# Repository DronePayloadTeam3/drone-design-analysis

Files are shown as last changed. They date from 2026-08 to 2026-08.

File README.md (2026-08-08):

# Solution to Classroom Challenge Project — Drone Payload Capacity and Structural Design Analysis — Team 3

MATLAB-based UAV arm design and optimization project using CAD modeling, thrust-to-weight analysis, finite element analysis (FEA), and material cost optimization to evaluate structural performance and payload capacity.

This project was completed as part of the MathWorks Classroom Challenge and demonstrates the application of CAD modeling, MATLAB programming, thrust-to-weight analysis, and finite element analysis (FEA) to optimize UAV drone arm performance.

---

# Project Objective

The objective of this project is to design and evaluate a quadcopter drone arm that maximizes payload capacity while maintaining safe flight performance and structural integrity. Two distinct drone arm geometries were evaluated using six different engineering materials through thrust-to-weight analysis and Finite Element Analysis (FEA).

Through the development and analysis of these designs, the project investigates how geometry and material selection affect payload capacity, factor of safety, material cost, structural displacement, and stress distribution (e.g., Von Mises stress). Through analytical calculations and computational modeling, this project identifies the drone arm design that best provides effective payload capacity and structural integrity while optimizing material cost.

---

# MATLAB is used throughout this project to:

* Perform thrust-to-weight analysis
* Perform Finite Element Analysis (FEA)
* Perform material cost optimization

---

# Repository Structure

## [CAD-Designs](https://github.com/DronePayloadTeam3/drone-design-analysis/tree/main/CAD-Designs)

Contains all CAD models and design sketches.

### [Design-1-Hollow-Tapered-Rectangular-Tube](https://github.com/DronePayloadTeam3/drone-design-analysis/tree/main/CAD-Designs/Design-1-Hollow-Tapered-Rectangular-Tube)

* [Design_1_CAD_Model.STEP](https://github.com/DronePayloadTeam3/drone-design-analysis/blob/main/CAD-Designs/Design-1-Hollow-Tapered-Rectangular-Tube/Design_1_CAD_Model.STEP)
* [Design_1_Concept_Sketch.pdf](https://github.com/DronePayloadTeam3/drone-design-analysis/blob/main/CAD-Designs/Design-1-Hollow-Tapered-Rectangular-Tube/Design_1_Concept_Sketch.pdf)
* [Visualization_Only_Model.STL](https://github.com/DronePayloadTeam3/drone-design-analysis/blob/main/CAD-Designs/Design-1-Hollow-Tapered-Rectangular-Tube/Visualization_Only_Model.STL) — STL export for visual purposes only on GitHub.

### [Design-2-Hollow-Truss-Structure](https://github.com/DronePayloadTeam3/drone-design-analysis/tree/main/CAD-Designs/Design-2-Hollow-Truss-Structure)

* [Design_2_CAD_Model.STL](https://github.com/DronePayloadTeam3/drone-design-analysis/blob/main/CAD-Designs/Design-2-Hollow-Truss-Structure/Design_2_CAD_Model.STL)
* [Design_2_Concept_Sketch.pdf](https://github.com/DronePayloadTeam3/drone-design-analysis/blob/main/CAD-Designs/Design-2-Hollow-Truss-Structure/Design_2_Concept_Sketch.pdf)

## [Documentation](https://github.com/DronePayloadTeam3/drone-design-analysis/tree/main/Documentation)

Contains supporting project documentation.

* [Drone_Design_Constraints_Assumptions_and_Ideas.xlsx](https://github.com/DronePayloadTeam3/drone-design-analysis/blob/main/Documentation/Drone_Design_Constraints_Assumptions_and_Ideas.xlsx) — Supporting project document containing initial drone design constraints, assumptions, material information, and related design resources used during development.
* [Drone_Payload_Team_3_TOA.pdf](https://github.com/DronePayloadTeam3/drone-design-analysis/blob/main/Documentation/Drone_Payload_Team_3_TOA.pdf) — Team agreement documenting the project's organization, responsibilities, and project expectations.

## [MATLAB](https://github.com/DronePayloadTeam3/drone-design-analysis/tree/main/MATLAB)

Contains all MATLAB files used throughout the project.

* [droneArmMaterials.mat](https://github.com/DronePayloadTeam3/drone-design-analysis/blob/main/MATLAB/droneArmMaterials.mat) — Material properties database used throughout the analysis.
* [DroneDesign_Team3_Analysis.mlx](https://github.com/DronePayloadTeam3/drone-design-analysis/blob/main/MATLAB/DroneDesign_Team3_Analysis.mlx) — Main MATLAB Live Script containing the complete drone design, analysis, and optimization workflow.

### [Live-Script-PDF-Exports](https://github.com/DronePayloadTeam3/drone-design-analysis/tree/main/MATLAB/Live-Script-PDF-Exports)

Contains PDF exports of the MATLAB Live Script analysis for each drone arm design.

* [Design_1_Live_Script_Analysis_Export.pdf](https://github.com/DronePayloadTeam3/drone-design-analysis/blob/main/MATLAB/Live-Script-PDF-Exports/Design_1_Live_Script_Analysis_Export.pdf) — PDF export of the MATLAB analysis using Design 1.
* [Design_2_Live_Script_Analysis_Export.pdf](https://github.com/DronePayloadTeam3/drone-design-analysis/blob/main/MATLAB/Live-Script-PDF-Exports/Design_2_Live_Script_Analysis_Export.pdf) — PDF export of the MATLAB analysis using Design 2.

## [Results](https://github.com/DronePayloadTeam3/drone-design-analysis/tree/main/Results)

Contains all exported project results organized by drone design.

* [Design-1-Results](https://github.com/DronePayloadTeam3/drone-design-analysis/tree/main/Results/Design-1-Results) — Contains maximum payload capacity, material cost optimization, and FEA results for Design 1.
* [Design-2-Results](https://github.com/DronePayloadTeam3/drone-design-analysis/tree/main/Results/Design-2-Results) — Contains maximum payload capacity, material cost optimization, and FEA results for Design 2.

An example of the exported FEA results is shown below for Design 1 using Fiberglass Composite (GFRP):

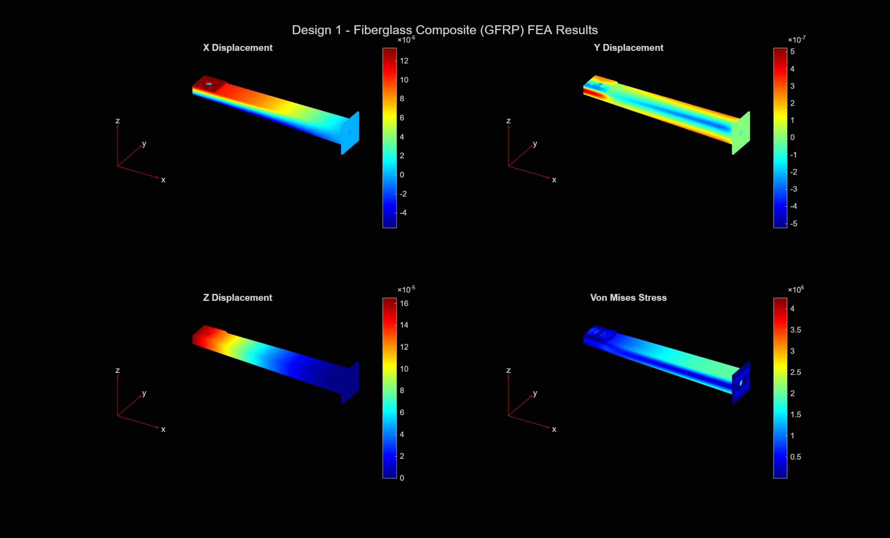
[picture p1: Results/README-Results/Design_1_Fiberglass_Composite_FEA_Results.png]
Design 1 Fiberglass Composite FEA Results


---

# CAD Download Instructions

1. Open the [CAD-Designs](https://github.com/DronePayloadTeam3/drone-design-analysis/tree/main/CAD-Designs) folder.
2. Open the [Design-1-Hollow-Tapered-Rectangular-Tube](https://github.com/DronePayloadTeam3/drone-design-analysis/tree/main/CAD-Designs/Design-1-Hollow-Tapered-Rectangular-Tube) or [Design-2-Hollow-Truss-Structure](https://github.com/DronePayloadTeam3/drone-design-analysis/tree/main/CAD-Designs/Design-2-Hollow-Truss-Structure) folder.
3. Select the desired STEP (for Design 1) or STL (for Design 2) file.
4. Click **Download Raw File** (download icon) in the upper-right corner.

   * Alternatively, right-click **Raw** and choose **Save Link As...**

**Note:** The `Visualization_Only_Model.STL` file for Design 1 is provided for visualization purposes only and is not intended to be used as the primary CAD model.

---

# Project Solution Instructions

1. Open MATLAB.

2. Place the project files in a working folder while maintaining the repository's file structure.

3. Open the [DroneDesign_Team3_Analysis.mlx](https://github.com/DronePayloadTeam3/drone-design-analysis/blob/main/MATLAB/DroneDesign_Team3_Analysis.mlx) Live Script.

4. Ensure the following files are available at their corresponding repository locations:

  * [droneArmMaterials.mat](https://github.com/DronePayloadTeam3/drone-design-analysis/blob/main/MATLAB/droneArmMaterials.mat)
  * [Design_1_CAD_Model.STEP](https://github.com/DronePayloadTeam3/drone-design-analysis/blob/main/CAD-Designs/Design-1-Hollow-Tapered-Rectangular-Tube/Design_1_CAD_Model.STEP)
  * [Design_2_CAD_Model.STL](https://github.com/DronePayloadTeam3/drone-design-analysis/blob/main/CAD-Designs/Design-2-Hollow-Truss-Structure/Design_2_CAD_Model.STL)

5. Select which drone arm design you would like to analyze during **Task 4: Finite Element Analysis (FEA)**.

   To switch between the two drone arm designs, locate the design selection in the Live Script.

   **For Design 1:**

   ```matlab
   selectedDesign = "Design 1";
   % selectedDesign = "Design 2";
   ```

   **For Design 2:**

   ```matlab
   % selectedDesign = "Design 1";
   selectedDesign = "Design 2";
   ```

   Only one design should remain uncommented before running the script. Design 1 is selected by default, as it is the final recommended design for this project.

6. Click **Run**.

The Live Script automatically generates:

* Payload summary tables
* Maximum payload comparison charts
* FEA displacement plots
* Von Mises stress plots
* FEA results tables
* Material cost comparison charts
* Material cost optimization tables
* Final design recommendation

All exported figures, tables, and analysis outputs can be found in the [Results](https://github.com/DronePayloadTeam3/drone-design-analysis/tree/main/Results) folder, organized separately for Design 1 and Design 2.

---

# Project Workflow

## 1. Gather Assumptions and Load Material Properties

Defines the drone design assumptions, component masses, thrust capacity, and project constraints, then loads the material properties used throughout the analysis.

The analysis considers six materials:

* Carbon Fiber Composite (CFRP)
* Aluminum Alloy
* Fiberglass Composite (GFRP)
* PLA Plastic
* ABS Plastic
* Wood (Birch)

The project parameters include:

* Quadcopter configuration with four motors and four propellers
* Maximum thrust of **1 kg per motor**
* Base drone mass of **1 kg**, excluding arms and payload
* Minimum payload requirement of **0.5 kg**
* Minimum thrust-to-weight ratio of **2:1**
* Four drone arms

Material properties used in the analysis include density, Young's modulus, Poisson's ratio, yield strength, and average material cost.

## 2. Propose Two Drone Arm Designs

Develops and compares two distinct drone arm geometries through CAD models and design sketches.

**Design 1** is a tapered hollow rectangular tube designed to strategically reduce material toward the motor mount while maintaining greater structural reinforcement near the drone body connection.

**Design 2** is a hollow truss-shaped structure designed to reduce mass while providing additional structural reinforcement through internal truss members.

The two designs are evaluated based on their geometry, volume, structural behavior, and suitability for the required loading conditions.

## 3. Perform Thrust-to-Weight Analysis

Calculates the maximum payload capacity for each combination of drone arm design and material.

The analysis evaluates both arm geometries across all six material options and determines whether each combination satisfies:

* Minimum payload requirement of **0.5 kg**
* Minimum thrust-to-weight ratio of **2:1**

The results are presented using summary tables and payload comparison plots.

## 4. Perform Finite Element Analysis (FEA)

Performs a structural finite element analysis on a single drone arm for the selected design.

The model:

* Imports the corresponding CAD geometry into MATLAB
* Generates a finite element mesh
* Fixes the arm at the attachment point to the drone body
* Applies the upward motor thrust and downward motor weight to the motor mounting face
* Evaluates the arm using all six material options

The analysis calculates:

* Maximum displacement
* Maximum Von Mises stress
* Factor of Safety

The results are presented using numerical summary tables and displacement and Von Mises stress visualizations.

## 5. Optimize Material Cost

Uses the results from the thrust-to-weight analysis and FEA to identify material options that satisfy the required payload, thrust-to-weight ratio, and Factor of Safety requirements.

The total material cost is then calculated for each material option based on the arm geometry, material cost, and four-arm configuration. The valid material options are compared to identify the lowest-cost solution while considering structural performance and engineering practicality.

## 6. Recommend a Final Design Solution

Interprets the results from the thrust-to-weight analysis, FEA, and material cost optimization to select the final drone arm geometry and material.

The final recommendation considers quantitative performance, structural safety, material cost, manufacturability, and practical engineering limitations.

---

# Required Software

* MATLAB R2026a

---

# Required Toolboxes

* Partial Differential Equation Toolbox

---

# References

* [MathWorks Classroom Challenge Project Hub: Drone Payload Capacity and Structural Design Analysis](https://github.com/mathworks/MATLAB-Simulink-Challenge-Project-Hub/tree/main/Classroom%20Challenge%20Projects/Projects/Drone%20Payload%20Capacity%20and%20Structural%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) — Original MathWorks Classroom Challenge project page containing the project challenge and associated project information.

* [Drone Design Constraints, Assumptions, and Ideas](https://github.com/DronePayloadTeam3/drone-design-analysis/blob/main/Documentation/Drone_Design_Constraints_Assumptions_and_Ideas.xlsx) — Supporting project document containing initial drone design constraints, assumptions, material information, and related design resources used during the development of the project.

* [Drone Payload Team 3 Team Agreement](https://github.com/DronePayloadTeam3/drone-design-analysis/blob/main/Documentation/Drone_Payload_Team_3_TOA.pdf) — Team agreement documenting the project's organization, responsibilities, and project expectations.

---

# Contact

For any questions regarding this repository or how to run the project, please contact the team at:

**[boulaetans@gmail.com](mailto:boulaetans@gmail.com)**

---

# License

This project is distributed under the license included in the repository.

See the [LICENSE](https://github.com/DronePayloadTeam3/drone-design-analysis/blob/main/LICENSE) file for the full license terms.

---

# Final Recommendation

Based on the thrust-to-weight analysis, Finite Element Analysis (FEA), and material cost optimization, the recommended design is **Design 1, a tapered hollow rectangular arm** constructed from **Fiberglass Composite (GFRP)**. It provides the best balance of payload capacity, structural safety, and engineering performance while satisfying all project constraints.

Although Carbon Fiber Composite (CFRP) provided the highest overall structural performance, GFRP offered a better balance between performance and cost while still meeting all project requirements. The improvements provided by CFRP were relatively small compared to its increase in material cost, making GFRP the more practical engineering choice.

Additionally, while Wood (Birch) was identified as the lowest-cost material, it was not selected as the final recommendation. Although it satisfied the project requirements under the simplified loading conditions, it was not considered the best choice for real-world drone applications where additional engineering conditions such as wind, vibration, fatigue, and landing impacts must be considered. Furthermore, wood can absorb moisture from the environment, which may reduce structural performance over time while increasing the overall weight of the drone. For these reasons, GFRP was considered the strongest overall engineering solution.

Compared with Design 2, Design 1 demonstrated better structural behavior. Although Design 2 met the project requirements, it experienced greater maximum displacement. Through investigation, it was determined that the truss members primarily reinforced the x- and y-directions but provided limited resistance in the z-direction. This reduced the arm's resistance to vertical bending and likely contributed to the higher displacement. Rather than redesigning the arm, the team chose to retain the original design because it demonstrates the engineering design process. The results highlighted how analysis, testing, and iteration lead to improved engineering decisions and provide valuable lessons for future designs.

Overall, Design 1 with GFRP provided the best combination of payload capacity, structural integrity, manufacturability, and material cost. Future work could expand this analysis by incorporating wind loading, vibration, fatigue, landing impacts, motor torque, and experimental prototype testing to better represent real operating conditions.

A more detailed report of the final design recommendation, including the MATLAB-based analysis, FEA results, and optimization process, can be found in the accompanying MATLAB Live Script.

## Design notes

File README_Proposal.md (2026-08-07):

# Drone-Design-Analysis-Team-3

MATLAB-based UAV arm design and optimization project using CAD modeling, thrust-to-weight analysis, finite element analysis (FEA), and material cost optimization to evaluate structural performance and payload capacity.

This project was completed as part of the MathWorks Classroom Challenge and demonstrates the application of CAD modeling, MATLAB programming, thrust-to-weight analysis, and finite element analysis (FEA) to optimize UAV drone arm performance.

---

# Project Objective

The objective of this project is to design and evaluate a quadcopter drone arm that maximizes payload capacity while maintaining safe flight performance and structural integrity. Two distinct drone arm geometries were evaluated using six different engineering materials through thrust-to-weight analysis and Finite Element Analysis (FEA).

Through the development and analysis of these designs, the project investigates how geometry and material selection affect payload capacity, factor of safety, material cost, structural displacement, and stress distribution (e.g., Von Mises stress). Through analytical calculations and computational modeling, this project identifies the drone arm design that best provides effective payload capacity and structural integrity while optimizing material cost.

---

# MATLAB is used throughout this project to:

- Perform thrust-to-weight analysis
- Perform Finite Element Analysis (FEA)
- Perform material cost optimization

---

# Repository Structure

## CAD-Designs

Contains all CAD models and design sketches.

- Design_1_CAD_Model.STEP
- Design_2_CAD_Model.STEP
- Design_1_Concept_Sketch.pdf
- Design_2_Concept_Sketch.pdf

## Documentation

Contains supporting project documentation.

- Team Agreement Form
- Initial assumptions and constraints
- Brainstorming and drone design concepts

## MATLAB

Contains all MATLAB files used throughout the project.

- DroneDesign_Team3_Analysis.mlx – Main MATLAB Live Script containing the complete drone design, analysis, and optimization workflow.
- DroneDesign1_Team3_Analysis.pdf – PDF export of the Design 1 MATLAB analysis.
- DroneDesign2_Team3_Analysis.pdf – PDF export of the Design 2 MATLAB analysis.
- droneArmMaterials.mat – Material properties database used throughout the analysis.

## Results

Contains all exported project results organized by drone design.

Each design folder contains:

- Charts
- FEA plots
- FEA result tables
- Maximum payload tables
- Material cost optimization tables

---

# How to Download the CAD Files

1. Open the **Drone CAD Designs** folder.
2. Select the desired STEP and STL file.
3. Click **Download Raw File** (download icon) in the upper-right corner.
4. Alternatively, right-click **Raw** and choose **Save Link As...**

---

# How to Run the Project

1. Open MATLAB.

2. Place all project files in the same working folder.

3. Open DroneDesign_Team3_Analysis.mlx.

4. Ensure the following files are located in the working directory:
- droneArmMaterials.mat
- Design_1_CAD_Model.STEP
- Design_2_CAD_Model.STL

6. Open **DroneDesign_Team3_Analysis.mlx**.

7. Select which drone arm design you would like to analyze during **Task 4: Finite Element Analysis (FEA)**.

To switch between the two drone arm designs, locate the STEP file assignment in the Live Script.

For Design 1:

```matlab
selectedDesign = "Design 1";
% selectedDesign = "Design 2";
```

For Design 2:

```matlab
% selectedDesign = "Design 1";
selectedDesign = "Design 2";
```

Only one design should remain uncommented before running the script.

6. Click **Run**.

---

# Project Workflow

## 1. Load Material Properties

Loads the density, Young's modulus, Poisson's ratio, yield strength, and material cost for:

- Carbon Fiber Composite (CFRP)
- Aluminum Alloy
- Fiberglass Composite (GFRP)
- PLA Plastic
- ABS Plastic
- Wood (Birch)

---

## 2. Thrust-to-Weight Analysis

Calculates the mass of each drone arm and determines the maximum payload capacity while verifying that each design satisfies:

- Minimum payload requirement of **0.5 kg**
- Minimum thrust-to-weight ratio of **2:1**

---

## 3. Finite Element Analysis (FEA)

Imports the selected STEP or STL model into MATLAB.

The script then:

- Generates the finite element mesh
- Applies boundary conditions
- Applies motor thrust and motor weight
- Computes:
  - Maximum displacement
  - Von Mises stress
  - Factor of Safety

The results are displayed as summary tables and interactive displacement and stress plots.

---

## 4. Material Cost Optimization

After completing the thrust-to-weight analysis and FEA, MATLAB calculates the material cost for each design based on the arm geometry and material properties.

The program filters materials that satisfy all project constraints and identifies the lowest-cost engineering solution.

---

# Required Software

- MATLAB R2026a

---

# Required Toolboxes

- Partial Differential Equation Toolbox
- MATLAB Live Editor

---

# How to Reproduce the Results

To reproduce the project results:

1. Use the provided **droneArmMaterials.mat** database.
2. Use the provided CAD models.
3. Open **DroneDesign_Team3_Analysis.mlx**.
4. Select either Design 1 or Design 2 by commenting/uncommenting the corresponding STEP file.
5. Run the Live Script without modifying any input parameters.

The Live Script automatically generates:

- Payload summary tables
- Maximum payload comparison charts
- Material cost comparison charts
- FEA displacement plots
- Von Mises stress plots
- FEA results tables
- Material cost optimization tables
- Final design recommendation

All exported figures, tables, and analysis outputs can be found in the **Results** folder, organized separately for Design 1 and Design 2.

---

# Final Recommendation

Based on the thrust-to-weight analysis, Finite Element Analysis (FEA), and material cost optimization, the recommended design is **Design 1, a tapered hollow rectangular arm** constructed from **Fiberglass Composite (GFRP)**. It provides the best balance of payload capacity, structural safety, and engineering performance while satisfying all project constraints.

Although Carbon Fiber Composite (CFRP) provided the highest overall structural performance, GFRP offered a better balance between performance and cost while still meeting all project requirements. The improvements provided by CFRP were relatively small compared to its increase in material cost, making GFRP the more practical engineering choice.

Additionally, while Wood (Birch) was identified as the lowest-cost material, it was not selected as the final recommendation. Although it satisfied the project requirements under the simplified loading conditions, it was not considered the best choice for real-world drone applications where additional engineering conditions such as wind, vibration, fatigue, and landing impacts must be considered. Furthermore, wood can absorb moisture from the environment, which may reduce structural performance over time while increasing the overall weight of the drone. For these reasons, GFRP was considered the strongest overall engineering solution.

Compared with Design 2, Design 1 demonstrated better structural behavior. Although Design 2 met the project requirements, it experienced greater maximum displacement. Through investigation, it was determined that the truss members primarily reinforced the x- and y-directions but provided limited resistance in the z-direction. This reduced the arm's resistance to vertical bending and likely contributed to the higher displacement. Rather than redesigning the arm, the team chose to retain the original design because it demonstrates the engineering design process. The results highlighted how analysis, testing, and iteration lead to improved engineering decisions and provide valuable lessons for future designs.

Overall, Design 1 with GFRP provided the best combination of payload capacity, structural integrity, manufacturability, and material cost. Future work could expand this analysis by incorporating wind loading, vibration, fatigue, landing impacts, motor torque, and experimental prototype testing to better represent real operating conditions.

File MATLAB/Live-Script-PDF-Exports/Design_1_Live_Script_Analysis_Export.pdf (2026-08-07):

## Drone Payload Structure Design and Analysis

In this project, you are optimizing drone arm design, including geometry and material selection, to maximize payload capacity while ensuring structural integrity under motor-induced loads. You will use MATLAB to perform force balance analysis and finite element modeling to quantitatively support your design solution.

Use this Live Script as a template to get started on your project solution. You may include helper functions at the bottom of this document or as separate files. For a tutorial on how to use Live Scripts, check out this video. (https://www.youtube.com/watch?v=hUXTyPYRidM)

Suggested Tasks

1. Gather your starter assumptions and load the material properties into MATLAB.
2. Propose at least two drone arm designs
3. Perform a thrust-to-weight analysis to evaluate each of your designs across all material options. Your design must meet a minimum payload requirement and safety standards.
4. Perform finite element analysis across all design and material options.
5. Recommend a final design solution.

Table of Contents

## Break Down the Problem

In the space below, define the problem statement:

The objective is to select a drone arm geometry and material combination that maximizes payload capacity while satisfying the minimum thrust-to-weight ratio and maintaining an acceptable structural safety factor under motor loading.

List the requirements, constraints, and success criteria for the project:

- The drone must support a minimum payload of 0.5 kg.
- The drone must meet a thrust-to-weight ratio of at least 2:1.
- The quadcopter configuration uses 4 motors and 4 propellers.
- Each motor can provide up to 1 kg of thrust.
- The total mass of the drone without arms or payload is 1 kg.
- The design must use at least two distinct arm geometries.
- The arm design must be evaluated across the available material options.
- The final selected design must satisfy the required payload and flight safety constraints.

- The structural design must maintain an acceptable factor of safety, with the target engineering range taken as approximately ~1.5-2+.
- Material cost should be considered as an optional optimization criterion in addition to the required performance and safety checks.

What is your proposed solution?

- The proposed solution is to compare two distinct drone arm geometries and evaluate them across the available material options using thrust-to-weight analysis and a single-arm finite element model to identify the combination that maximizes payload capacity while satisfying the required flight and structural safety constraints.

List the steps you will need to take to achieve your proposed solution:

1. Gather Starter Assumptions and Load Properties into MATLAB
2. Develop at Least Two Distinct Drone Arm Designs in CAD or by Hand
3. Write a MATLAB Function to Perform a Thrust-to-Weight Analysis Across All Design and Material Options
4. Create a 3D Model of One Drone Arm Using CAD Software of Your Choice
5. Import Your Model into MATLAB and Perform FEA
6. Report the Overall Maximum Displacement, Maximum Stress, and Factor of Safety for Each Design and Material Combination, Including Visualizations of the X-, Y-, and Z-Displacement and von Mises Stress
7. Recommend a Final Drone Arm Design That Meets All Required Constraints

What challenges do you face in the process of achieving the solution?

- The analysis is simplified to a single-arm structural model rather than the full four-arm drone assembly.
- Material properties are treated as homogeneous and isotropic, which is an approximation for composite and wood materials.
- The arm geometry and loading conditions are idealized rather than fully representing the complete flight environment.
- The FEA model captures only the dominant motor thrust and motor weight loading, while other real-world effects such as vibration, landing loads, and aerodynamic forces are not included.
- The design must balance payload capacity, structural stiffness, and material cost under the stated assumptions.

## Task 1: Gather your starter assumptions and load material properties

Load the provided droneArmMaterials.mat file into MATLAB. This contains a data struct with the material properties for six different materials commonly used for drones (carbon fiber composite, aluminum alloy, fiberglass composite, PLA plastic, ABS plastic, and wood). For each material, you have been provided the following information:

▪
Density ( ), in

- Young's Modulus (E) in Pa
- Poisson's ratio ( ), unitless
- Yield strength, in Pa
- Average cost per meter in US dollars

For this project, you can assume the following design parameters:

- Quadcopter drone with 4 motors and 4 propellers
- Each motor can provide up to 1kg thrust
▪
Acceleration due to gravity:
- Total weight of the drone components without the arms or the payload: 1kg

The breakdown of the weight of each drone component is as follow:

- Battery = 0.3kg
- Each motor = 65g, 4 motors = 0.26kg
- Each propeller = 10g, 4 propellers = 0.04 kg
- Each electronic speed controller = 30g, 4 electronic speed controllers = 0.12 kg
- Flight controller and electronics = 0.05kg
- Receiver/GPS = 0.03kg
- Drone frame (center body) excluding arms = 0.2kg

clc; clear; close all;

% Load material properties for the six drone arm materials load droneArmMaterials.mat;

% Define drone component masses (kg)
batteryMass = 0.30; % Battery
motorMass = 65 / 1000; % Each motor numberOfMotors = 4; % Number of motors totalMotorMass = motorMass * numberOfMotors;

propellerMass = 10 / 1000; % Each propeller
numberOfPropellers = 4; % Number of propellers
totalPropellerMass = propellerMass * numberOfPropellers;

speedControllerMass = 30 / 1000; % Each electronic speed controller numberOfSpeedControllers = 4; % Number of electronic speed controllers totalSpeedControllerMass = ...
speedControllerMass * numberOfSpeedControllers;

flightControllerMass = 0.05; % Flight controller and electronics receiverGPSMass = 0.03; % Receiver/GPS
droneFrameMass = 0.20; % Drone frame excluding arms

% Calculate total mass of the drone without arms or payload totalDroneMassWithoutArmsOrPayload = ...
batteryMass + ...
totalPropellerMass + ...
totalMotorMass + ...
totalSpeedControllerMass + ... flightControllerMass + ... receiverGPSMass + ...
droneFrameMass;

% Define general design parameters
gravity = 9.81; % Acceleration due to gravity (m/s^2) motorThrustCapacity = 1; % Maximum thrust per motor (kgf)
totalThrust = numberOfMotors * motorThrustCapacity;
minimumPayload = 0.5; % Minimum required payload (kg) requiredThrustToWeightRatio = 2; % Required thrust-to-weight ratio (2:1) numberOfArms = 4; % Number of arms on the quadcopter

## Task 2: Propose at least two drone arm designs

Develop at least two distinct drone arm designs by drawing clear, neatly labeled sketches that show key geometric features, including:

- Overall shape (e.g. beam, tube, truss structure)
- Dimensions (length, width, thickness)
- Motor mount location
- Where the arm connects to the drone body

The two designs should be meaningfully different from each other (e.g. different geometries or structural strategies) and not just small variations of the same idea.

Navigate to the 'Insert' tab and insert pictures of your sketches in the space below (hand-drawn or digital). Include a short design description for each sketch that includes:

- Geometry (e.g. solid beam, hollow tube, beam with trusses)
- Why you chose this design
- How it might perform under load

Note: All dimensions and measurements for the drone arm designs are provided in millimeters (mm) for consistency.

Drone Arm Design 1:

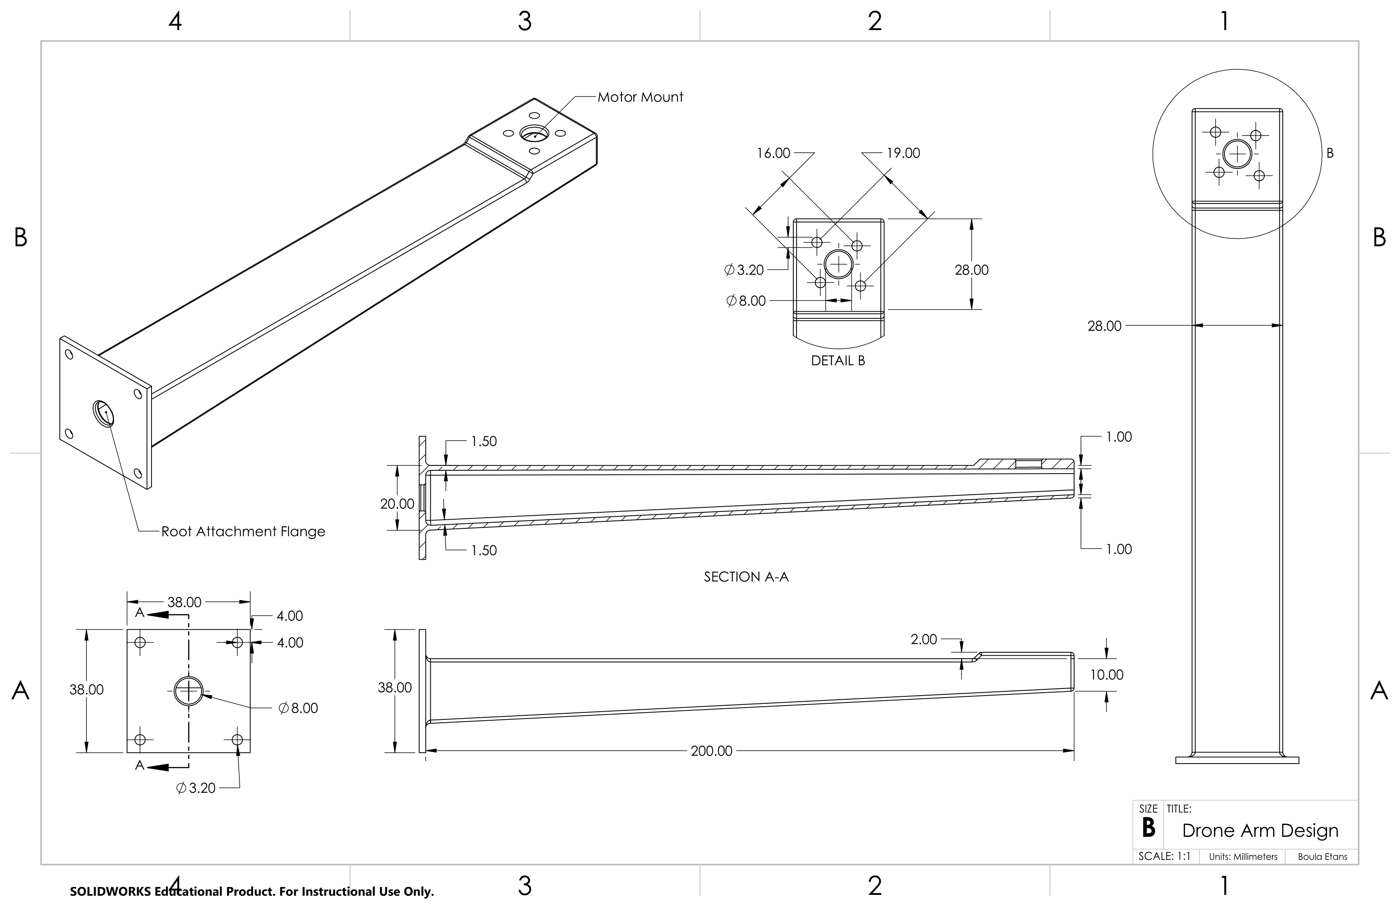
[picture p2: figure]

Geometry: A tapered hollow rectangular tube spanning a total length of 200.00 mm. The structure originates at the base with a 38.00 mm by 38.00 mm square attachment flange and a profile measuring 28.00 mm in width and 20.00 mm in height, featuring a wall thickness of 1.50 mm. It gracefully tapers toward the distal end to a profile measuring 28.00 mm in width and 10.00 mm in height, with a reduced wall thickness of 1.00 mm. The arm terminates in a 28.00 mm by 28.00 mm square motor mount platform positioned 2.00 mm above the top edge of the tapered body.

Reasoning: This geometry is chosen to optimize the strength-to-weight ratio. A drone arm acts as a cantilever beam, meaning the highest bending moments occur at the base where it attaches to the frame, while the stresses at the motor end are significantly lower. By tapering both the overall profile and the wall thickness, the design strategically places material only where it is needed to bear the load, stripping away unnecessary dead weight at the tip.

Analysis: Under the 1 kg upward thrust load, this arm is expected to show excellent bending stiffness at
the root, keeping overall deflections low. Because the tapered design minimizes the arm's total mass, it will consume less of the drone's 2 to 1 thrust-to-weight budget, maximizing the remaining capacity available to safely carry the required 0.5 kg payload.

Drone Arm Design 2:

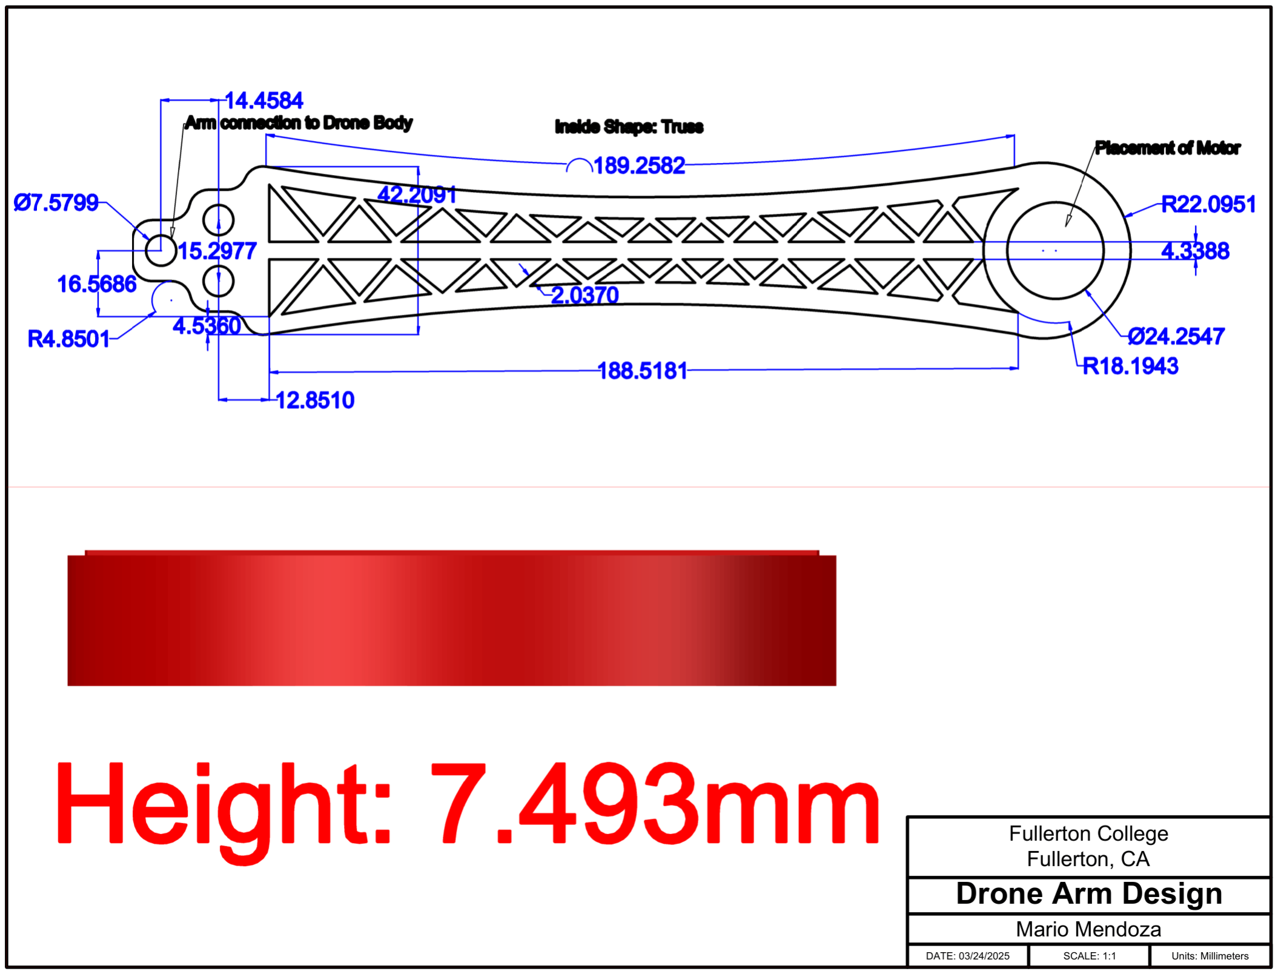
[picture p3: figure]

Geometry: A hollow, truss-shaped interior where each truss arm or branch has a thickness of approximately 2.0370 mm. The outside walls feature a continuous inward curve (with a radius of 189.2582 mm), causing the internal truss structure to narrow towards the middle before widening again as it approaches the motor housing. Holes for the arm connection are placed in a triangle shape. The total height of the drone arm is 7.493 mm throughout.

Reasoning: Truss shapes of the inside part of the drone arm are designed for stabilization, optimal strength, material efficiency, and weight reduction. This drone arm design also allows for creativity of the user or any future re-designers regarding the placement of the motor. The arm connection to the body of the drone is also shaped in a triangle to ensure the placement is optimally secured and geometrically rigid.

Analysis: While the truss structure of the drone arm design will provide strength and stiffness, the region between the arm connection and the starting portion of where the curvature begins might cause future problems; further optimization might be required in order to avoid a snap of that region.

## Task 3: Perform thrust-to-weight analysis across all design and material options

Write a MATLAB function that will perform a thrust-to-weight analysis across all design and material options. This analysis will help you evaluate which drone arm design and which material optimizes payload capacity while meeting suggested safety requirements.

- Your design must support a minimum payload of 0.5kg.
- Your design must meet a thrust-to-weight ratio of at least 2:1 to ensure safe and stable flight. This safety standard is widely used in drone design. Conceptually, it means that the drone's maximum thrust must be at least twice its weight. This ensures stable hovering and maneuvering with a safety margin. Note that the thrust-to-weight safety margin is a system-level safety standard for drone flight that is distinct from the structural safety factor of the drone arms (which you will evaluate later through finite element analysis).
- Your goal is calculate maximum payload capacity for each design and material option (i.e. what is the heaviest payload your drone design could carry while still allowing the drone to safely take off?)

Ensure that the results of your analysis can be readily interpreted, e.g. in the form of a summary table or plot.

Note: if you have two drone arm designs, the expected output should be 12 payload capacity estimates (2 designs across 6 materials options).

% Define arm volumes from Task 2
armVolume1 = 2.483207e-5;
armVolume2 = 3.4295614e-5;

% Store both design volumes for comparison armVolumes = [armVolume1, armVolume2];

% Define names for each drone arm design
designNames = ["Design 1", "Design 2"];

% Perform thrust-to-weight analysis for all designs and materials task3Results = thrustToWeightAnalysis( ...
armVolumes, ...
designNames, ...
materials, ...
totalDroneMassWithoutArmsOrPayload, ... totalThrust, ...
minimumPayload, ...
requiredThrustToWeightRatio, ... numberOfArms);

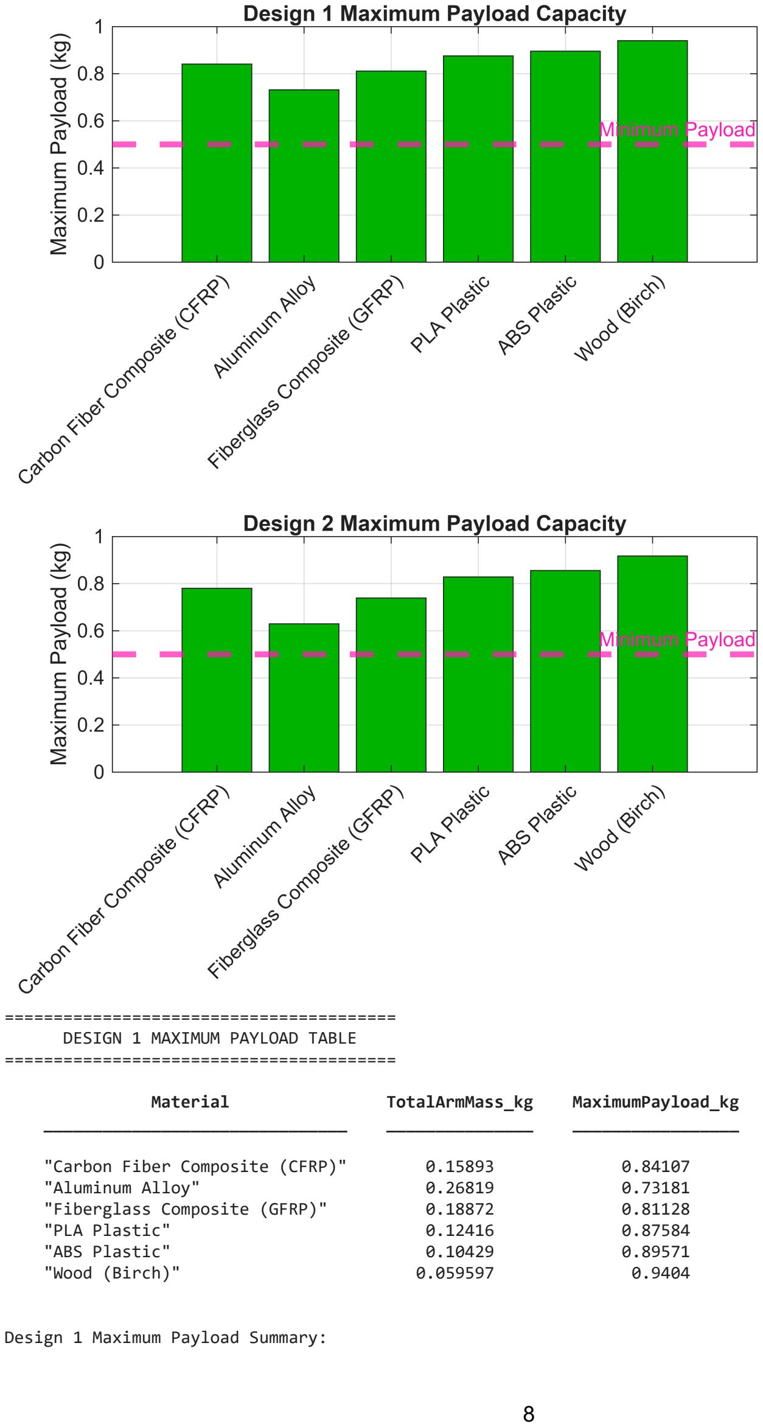
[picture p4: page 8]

======================================== DESIGN 1 MAXIMUM PAYLOAD TABLE ========================================

Material | TotalArmMass_kg | MaximumPayload_kg
_______________________________ | _______________ | _________________
"Carbon Fiber Composite (CFRP)" | 0.15893 | 0.84107
"Aluminum Alloy" | 0.26819 | 0.73181
"Fiberglass Composite (GFRP)" | 0.18872 | 0.81128
"PLA Plastic" | 0.12416 | 0.87584
"ABS Plastic" | 0.10429 | 0.89571
"Wood (Birch)" | 0.059597 | 0.9404

Design 1 Maximum Payload Summary:

Design 1 Passes for:
Carbon Fiber Composite (CFRP) Aluminum Alloy
Fiberglass Composite (GFRP) PLA Plastic
ABS Plastic
Wood (Birch)

Design 1 Fails for:
No materials failed

======================================== DESIGN 2 MAXIMUM PAYLOAD TABLE ========================================

Material | TotalArmMass_kg | MaximumPayload_kg
_______________________________ | _______________ | _________________
"Carbon Fiber Composite (CFRP)" | 0.21949 | 0.78051
"Aluminum Alloy" | 0.37039 | 0.62961
"Fiberglass Composite (GFRP)" | 0.26065 | 0.73935
"PLA Plastic" | 0.17148 | 0.82852
"ABS Plastic" | 0.14404 | 0.85596
"Wood (Birch)" | 0.082309 | 0.91769

Design 2 Maximum Payload Summary:

Design 2 Passes for:
Carbon Fiber Composite (CFRP) Aluminum Alloy
Fiberglass Composite (GFRP) PLA Plastic
ABS Plastic
Wood (Birch)

Design 2 Fails for:
No materials failed

function task3Results = thrustToWeightAnalysis( ... armVolumes, designNames, materials, ... totalDroneMassWithoutArmsOrPayload, ... totalThrust, minimumPayload, ...
requiredThrustToWeightRatio, ...
numberOfArms)

% Determine the number of materials and design-material combinations numberOfMaterials = length(materials);
numberOfCombinations = length(armVolumes) * numberOfMaterials;

% Initialize arrays for storing analysis results
designNameResults = strings(numberOfCombinations, 1); materialNameResults = strings(numberOfCombinations, 1); armDensity = zeros(numberOfCombinations, 1); totalArmMass = zeros(numberOfCombinations, 1); maximumPayload = zeros(numberOfCombinations, 1); resultStatus = strings(numberOfCombinations, 1);

% Calculate the maximum allowable drone mass based on the required thrust-to-weight ratio
maximumAllowedTotalMass = totalThrust / requiredThrustToWeightRatio;

% Initialize combination counter
combinationNumber = 1;

% Loop through each arm design
for designNumber = 1:length(armVolumes)

% Get the current arm volume currentArmVolume = armVolumes(designNumber);

% Loop through each material option
for materialNumber = 1:numberOfMaterials

% Store current design and material information designNameResults(combinationNumber) = designNames(designNumber); materialNameResults(combinationNumber) = string(materials(materialNumber).name); armDensity(combinationNumber) = materials(materialNumber).rho_kg_m3;

% Calculate the total mass of all four drone arms totalArmMass(combinationNumber) = ...
currentArmVolume * armDensity(combinationNumber) * numberOfArms;

% Calculate the maximum payload capacity for the current design-material combination
maximumPayload(combinationNumber) = ...
maximumAllowedTotalMass - ... totalDroneMassWithoutArmsOrPayload - ... totalArmMass(combinationNumber);

% Calculate the total drone mass including the minimum payload totalDroneMass = ...
totalDroneMassWithoutArmsOrPayload ...
+ totalArmMass(combinationNumber) ...
+ minimumPayload;

% Check if the design satisfies payload and thrust-to-weight requirements
if maximumPayload(combinationNumber) >= minimumPayload && ... totalThrust / totalDroneMass >= requiredThrustToWeightRatio

resultStatus(combinationNumber) = "PASS";

else

resultStatus(combinationNumber) = "FAIL";

end

% Move to the next design-material combination combinationNumber = combinationNumber + 1;

end
end

% Create a complete table containing all internal analysis results fullTable = table( ...
designNameResults, ...
materialNameResults, ...
armDensity, ...
totalArmMass, ...
maximumPayload, ...
'VariableNames', { ...
'Design', ...
'Material', ...
'Density_kg_m3', ...
'TotalArmMass_kg', ...
'MaximumPayload_kg'});

% Save internal results for later use in Task 5 task3Results.designNames = designNameResults; task3Results.materialNames = materialNameResults; task3Results.maximumPayload = maximumPayload; task3Results.resultStatus = resultStatus;

% Extract display tables for each individual design design1Display = fullTable( ...
fullTable.Design == "Design 1", ...
{'Material', 'TotalArmMass_kg', 'MaximumPayload_kg'}); design2Display = fullTable( ...
fullTable.Design == "Design 2", ...
{'Material', 'TotalArmMass_kg', 'MaximumPayload_kg'});

% Create a payload comparison plot for each design
for designNumber = 1:length(designNames)

% Create a new figure for the current design
figure;

% Identify results belonging to the current design designIndex = designNameResults == designNames(designNumber); designPayload = maximumPayload(designIndex);
designStatus = resultStatus(designIndex);
designMaterials = materialNameResults(designIndex);

% Create bar plot of maximum payload capacity barHandle = bar(designPayload);

% Initialize colors based on pass or fail status
plotColors = zeros(numberOfMaterials, 3);

% Assign green to passing materials and red to failing materials for materialNumber = 1:numberOfMaterials

if designStatus(materialNumber) == "PASS" plotColors(materialNumber, :) = [0 0.7 0];

else
plotColors(materialNumber, :) = [0.9 0 0];

end

end

% Apply colors to the bar chart barHandle.FaceColor = "flat"; barHandle.CData = plotColors;

% Format x-axis labels
xticks(1:numberOfMaterials); xticklabels(designMaterials); xtickangle(45);

% Add plot labels and title
ylabel("Maximum Payload (kg)"); title(designNames(designNumber) + " Maximum Payload Capacity");

% Display minimum payload requirement
yline(minimumPayload, "--", "Minimum Payload", ...
"Color", [1 0.1 0.7], "LineWidth", 3);

% Set plot limits and enable grid
ylim([0 1]);
yticks(0:0.2:1);
grid on;

end

% Display Design 1 results
fprintf("\n");
fprintf("========================================\n"); fprintf(" DESIGN 1 MAXIMUM PAYLOAD TABLE\n"); fprintf("========================================\n\n"); disp(design1Display);

% Design 1 Summary:

fprintf("\nDesign 1 Maximum Payload Summary:\n");

design1Payload = maximumPayload(1:numberOfMaterials); design1Materials = materialNameResults(1:numberOfMaterials);

% Design 1 passes
fprintf("\nDesign 1 Passes for:\n");

design1Passed = false;

for i = 1:numberOfMaterials
if design1Payload(i) >= minimumPayload fprintf(" %s\n", design1Materials(i)); design1Passed = true;
end
end

if ~design1Passed
fprintf(" No materials passed\n"); end

% Design 1 fails
fprintf("\nDesign 1 Fails for:\n");

design1Failed = false;

for i = 1:numberOfMaterials
if design1Payload(i) < minimumPayload fprintf(" %s\n", design1Materials(i)); design1Failed = true;
end
end

if ~design1Failed
fprintf(" No materials failed\n"); end

% Display Design 2 results
fprintf("\n");
fprintf("========================================\n"); fprintf(" DESIGN 2 MAXIMUM PAYLOAD TABLE\n"); fprintf("========================================\n\n"); disp(design2Display);

% Design 2 Summary:
fprintf("\nDesign 2 Maximum Payload Summary:\n");

design2Payload = maximumPayload(numberOfMaterials+1:2*numberOfMaterials); design2Materials = materialNameResults(numberOfMaterials+1:2*numberOfMaterials);

% Design 2 passes
fprintf("\nDesign 2 Passes for:\n");

design2Passed = false;

for i = 1:numberOfMaterials
if design2Payload(i) >= minimumPayload fprintf(" %s\n", design2Materials(i)); design2Passed = true;
end
end

if ~design2Passed
fprintf(" No materials passed\n"); end

% Design 2 fails
fprintf("\nDesign 2 Fails for:\n");

design2Failed = false;

for i = 1:numberOfMaterials
if design2Payload(i) < minimumPayload fprintf(" %s\n", design2Materials(i)); design2Failed = true;
end
end

if ~design2Failed
fprintf(" No materials failed\n"); end
end

## Task 4: Perform finite element analysis across all design and material options

Perform finite element analysis (FEA) across all design and material options to evaluate the structural safety factor of your drone arm design. To simplify the task, you will perform the FEA only on a single drone arm.

Using a CAD software of your choice, first create a 3D model of one drone arm for each of your designs. Be sure your model can be exported as a STEP or STL file for analysis in MATLAB.

- Recommended CAD software options: Tinkercad, Onshape, Fusion 360, Solidworks (most have free versions)

Import your model into MATLAB and perform FEA. In your FEA model, you should model and apply two loads to the drone arm: upward thrust force from the motor and downward weight of the motor.

- Helpful resources: online tutorial, (https://matlabacademy.mathworks.com/details/introduction-to-finite-element-analysis-with-matlab/otmlfea) documentation for Structural Mechanics (https://www.mathworks.com/help/pde/structural-mechanics.html) and Partial Differentiation Equation Toolbox, (https://www.mathworks.com/help/pde/index.html?s_tid=CRUX_lftnav) and example workflow (https://www.mathworks.com/help/pde/ug/deflection-analysis-of-bracket-femodel.html)

For the chosen design and each material combination, you should report the overall maximum displacement, maximum stress, and factor of safety and include visualizations of the x-, y-, and z-displacement and Von
Mises stress. Ensure that your results are presented for easy interpretation (e.g. present a table with numerical results, clearly labeled subplots for the visualizations).
- The factor of safety compares how strong a material is to how much stress it experiences, indicating whether
a design is safe under the given loads. For this project use the equation: | .

Yield strength indicates how much stress a given material can withstand before permanently deforming. Maximum von Mises stress (derived from your FEA model) is a measure of how much stress your design experiences under the applied loads.
- A typical engineering safety margin for FoS is ~1.5-2+
- This example (https://www.mathworks.com/help/pde/ug/deflection-analysis-of-bracket-femodel.html) demonstrates the plots you are asked to include in your results

% STEP 1: Import drone arm geometry into MATLAB, visualize the geometry to % identify key faces (e.g. tip face)

% Select which drone arm design to analyze.
% By default, Design 1 will run.
% To run Design 2, comment out the first line below and uncomment the second.
% Ensure the corresponding CAD file is in the same directory as this Live Script. selectedDesign = "Design 1";
% selectedDesign = "Design 2";

if selectedDesign == "Design 1"

CADfile = "Design_1_CAD_Model.STEP"; fixedFaceID = 24;
motorMountFaceID = 33;
motorMountFaceArea = 0.00062144;

elseif selectedDesign == "Design 2"

CADfile = "Design_2_CAD_Model.STL"; fixedFaceID = 111;
motorMountFaceID = 82;
motorMountFaceArea = 0.000866359;

end

% Initialize the finite element model using the geometry
modelFE = femodel(AnalysisType="structuralStatic", Geometry=CADfile);

% Apply STL scaling only for Design 2
if selectedDesign == "Design 2"
modelFE.Geometry = scale(modelFE.Geometry,0.001); end

% Generate the finite element mesh
modelFE = generateMesh(modelFE, Hmax=1.5e-3);

% Plot the geometry and display face labels
% This allows the fixed base and motor mount faces to be identified figure;

pdegplot(modelFE, FaceLabels="on", FaceAlpha=0.5);

view(30, 30);
axis equal;
title(selectedDesign + " Drone Arm Face Labels");

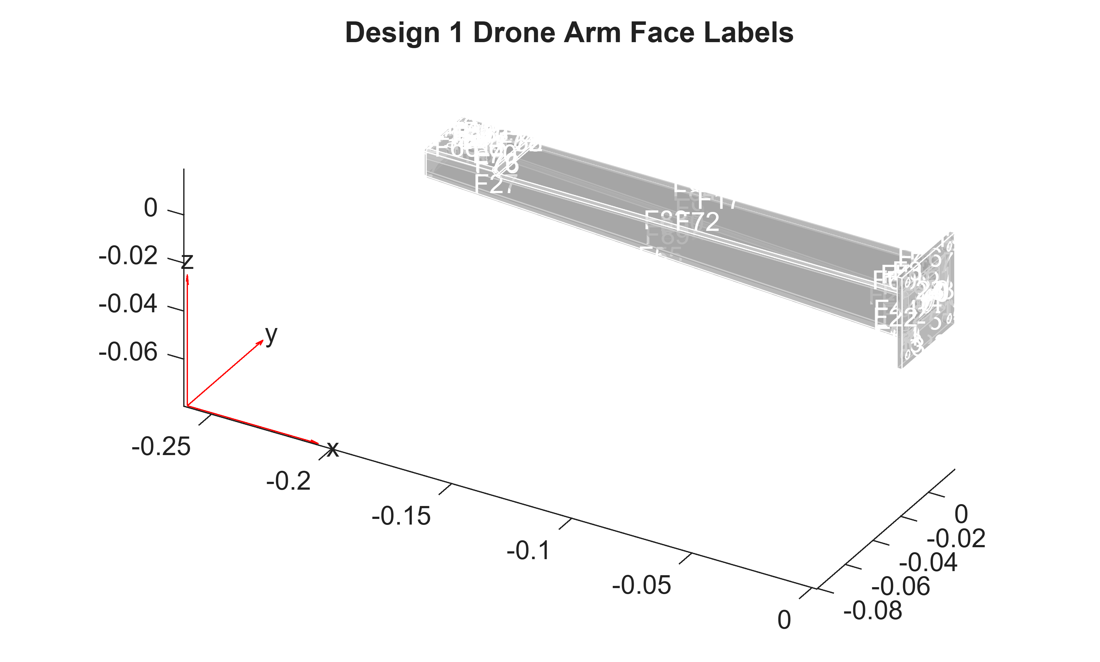
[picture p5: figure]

% IMPORTANT:
% Visually confirm from this face-label plot that the selected face IDs % correspond to the intended physical locations

% STEP 2: Define material properties

% Get the number of available materials
numberOfMaterials = length(materials);

% Initialize arrays for storing FEA results for all six materials materialName = strings(numberOfMaterials, 1);

maximumDisplacementResults = zeros(numberOfMaterials, 1); maximumVonMisesStressResults = zeros(numberOfMaterials, 1); factorOfSafetyResults = zeros(numberOfMaterials, 1);
resultStatus = strings(numberOfMaterials, 1);

% STEP 3: Apply boundary conditions (fix base of arm where it would be % attached to drone body)

modelFE.FaceBC(fixedFaceID) = ...
faceBC(Constraint="fixed");

% STEP 4: Apply the upward thrust force (motor force)
% Define the thrust force, convert force to surface traction, apply
% surface traction to the appropriate face in the appropriate direction

% Calculate the upward thrust force from the motor
motorThrustForce_N = motorThrustCapacity * gravity;

% STEP 5: Apply downward motor weight
% Define motor weight, convert to traction, apply to the appropriate face % in the appropriate direction

% Calculate the downward weight of the motor
motorWeightForce_N = motorMass * gravity;

% Calculate the net force acting in the loading direction
% The upward motor thrust is positive and the downward motor weight is % negative
netForceZ_N = motorThrustForce_N - motorWeightForce_N;

% IMPORTANT:
% SurfaceTraction is specified in the global Cartesian coordinate system % The current model assumes that positive global Z is the upward thrust % direction based on the STEP model coordinate orientation

thrustDirection = [0; 0; 1];

% Calculate the net surface traction
netTractionMagnitude = netForceZ_N / motorMountFaceArea;

% Convert the scalar net traction into a global Cartesian vector netTraction = thrustDirection * netTractionMagnitude;

% Apply the combined net traction to the motor mount face modelFE.FaceLoad(motorMountFaceID) = faceLoad(SurfaceTraction=netTraction);

% STEP 6: Solve the FEA model for materialNumber = 1:numberOfMaterials

% Print the current material being processed
fprintf("Running FEA for material %d/%d: %s\n", ...
materialNumber, numberOfMaterials, string(materials(materialNumber).name)); drawnow;

% Get material information from the droneArmMaterials data structure materialName(materialNumber) = string(materials(materialNumber).name);

YoungsModulus = materials(materialNumber).E_Pa;
PoissonsRatio = materials(materialNumber).nu;
YieldStrength = materials(materialNumber).yieldStrength_Pa;

% Assign material properties to the finite element model currentModel = modelFE;

currentModel.MaterialProperties = materialProperties( ... YoungsModulus=YoungsModulus, ... PoissonsRatio=PoissonsRatio);

% Solve the FEA model for the current material
results = solve(currentModel);

% STEP 7: Get numerical results

% Calculate displacement magnitude at every mesh node displacementMagnitude = sqrt( ... results.Displacement.ux.^2 + ... results.Displacement.uy.^2 + ... results.Displacement.uz.^2);

% Calculate the maximum displacement magnitude maximumDisplacement = max(displacementMagnitude);

% Calculate the maximum Von Mises stress maximumVonMisesStress = max(results.VonMisesStress);

% Calculate the factor of safety
factorOfSafety = YieldStrength / maximumVonMisesStress;

% Store numerical results (conversion of units) maximumDisplacementResults(materialNumber) = maximumDisplacement * 1000; maximumVonMisesStressResults(materialNumber) = maximumVonMisesStress / 1e6; factorOfSafetyResults(materialNumber) = factorOfSafety;

% Determine whether the design meets the recommended
% minimum factor of safety of 1.5
if factorOfSafety >= 1.5 resultStatus(materialNumber) = "SAFE"; else
resultStatus(materialNumber) = "UNSAFE"; end

% STEP 8: Visualize your results
figure;
sgtitle(selectedDesign + " - " + materialName(materialNumber) + " FEA Results");

subplot(2,2,1);
pdeplot3D(results.Mesh, ColorMapData=results.Displacement.ux);
title("X Displacement");
xlabel("X");
ylabel("Y");
zlabel("Z");
axis equal;
colormap(gca, "jet");
colorbar;

subplot(2,2,2);
pdeplot3D(results.Mesh, ColorMapData=results.Displacement.uy); title("Y Displacement");
xlabel("X");
ylabel("Y");
zlabel("Z");
axis equal;
colormap(gca, "jet");
colorbar;

subplot(2,2,3);
pdeplot3D(results.Mesh, ColorMapData=results.Displacement.uz); title("Z Displacement");
xlabel("X");
ylabel("Y");
zlabel("Z");
axis equal;
colormap(gca, "jet");
colorbar;

subplot(2,2,4);
pdeplot3D(results.Mesh, ColorMapData=results.VonMisesStress); title("Von Mises Stress");
xlabel("X");
ylabel("Y");
zlabel("Z");
axis equal;
colormap(gca, "jet");
colorbar;

end

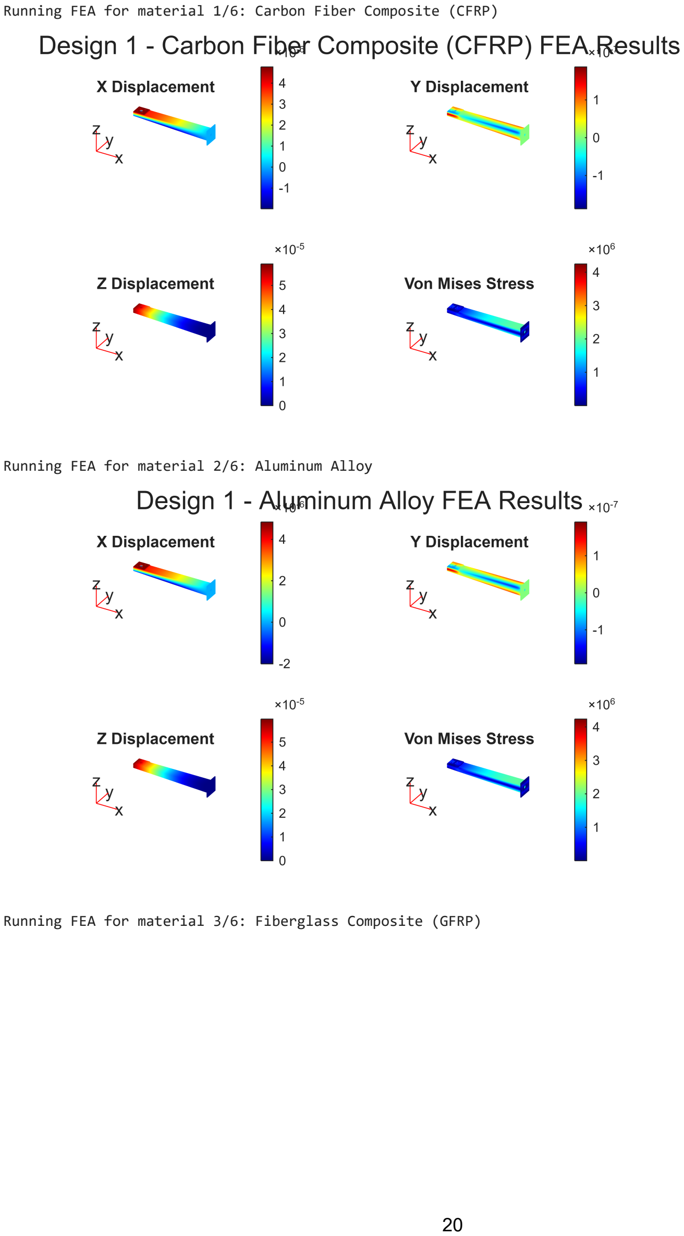
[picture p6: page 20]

Running FEA for material 1/6: Carbon Fiber Composite (CFRP)

Running FEA for material 2/6: Aluminum Alloy

Running FEA for material 3/6: Fiberglass Composite (GFRP)

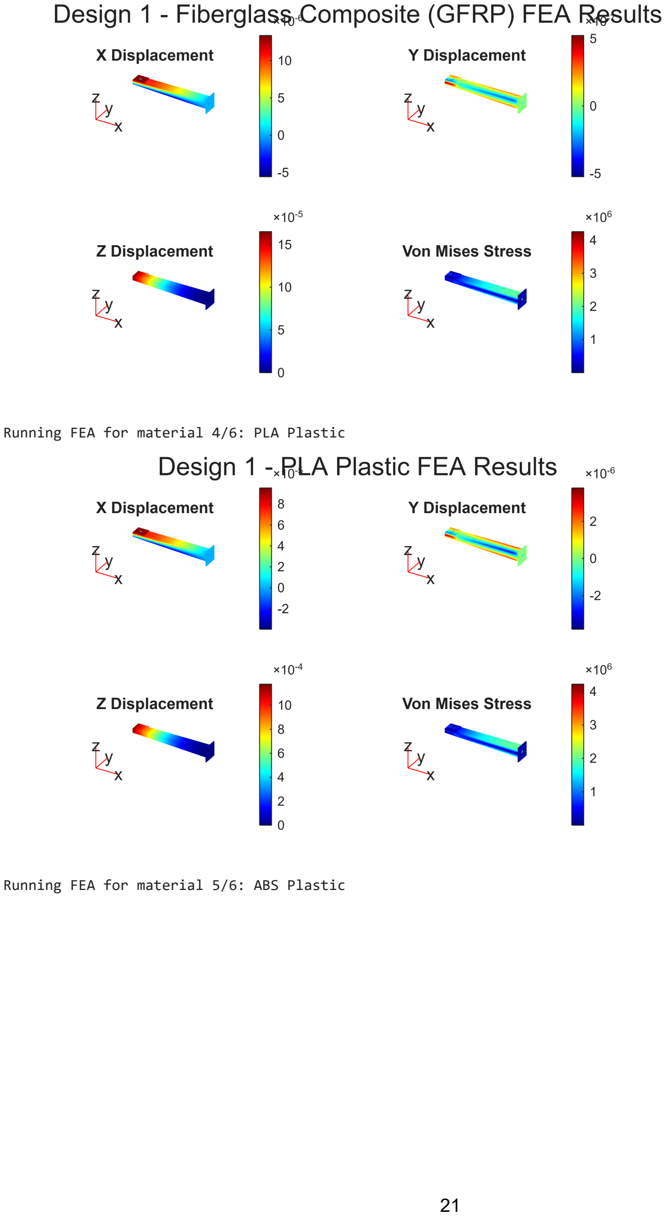
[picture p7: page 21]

Running FEA for material 4/6: PLA Plastic

Running FEA for material 5/6: ABS Plastic

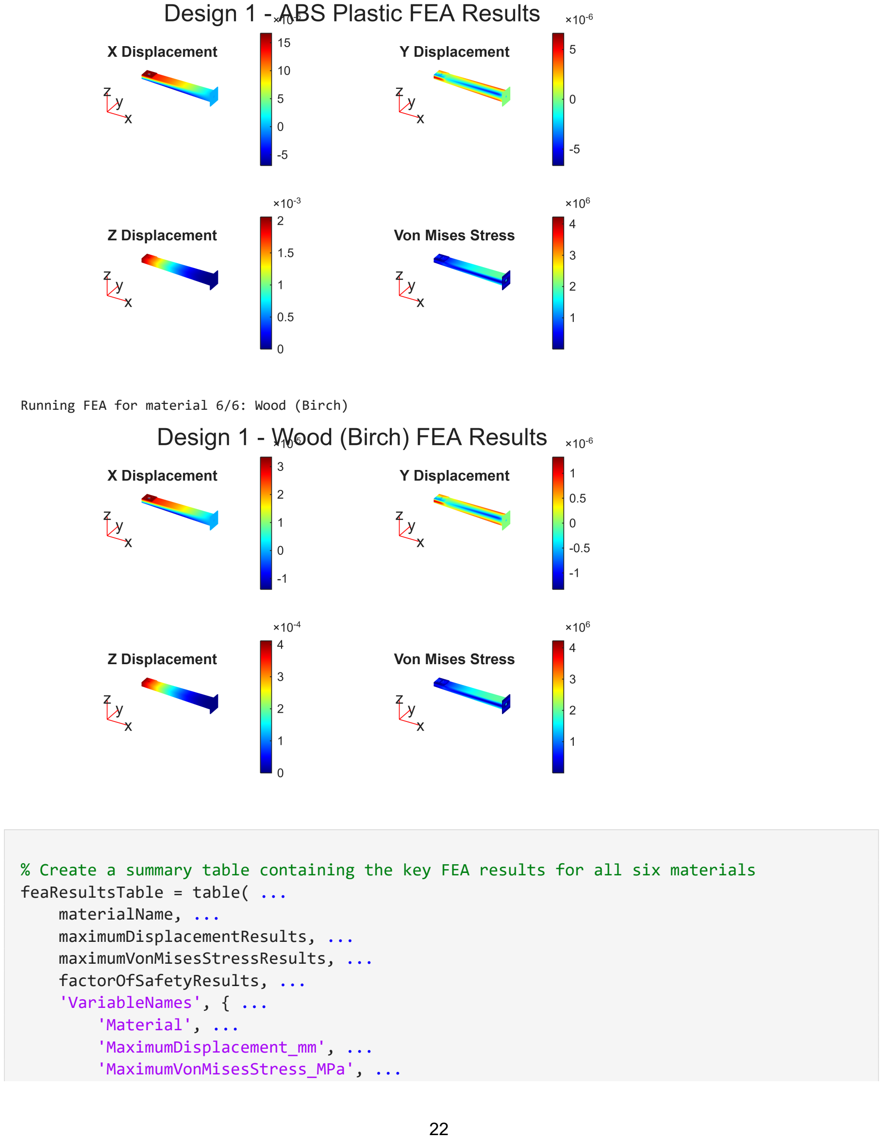
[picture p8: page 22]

Running FEA for material 6/6: Wood (Birch)

% Create a summary table containing the key FEA results for all six materials feaResultsTable = table( ...
materialName, ...
maximumDisplacementResults, ...
maximumVonMisesStressResults, ... factorOfSafetyResults, ... 'VariableNames', { ...
'Material', ...
'MaximumDisplacement_mm', ... 'MaximumVonMisesStress_MPa', ...

'FactorOfSafety'});

% Save complete internal results for later use in Task 5 task4Results.materialNames = materialName; task4Results.factorOfSafety = factorOfSafetyResults; task4Results.resultStatus = resultStatus;

% Display the FEA summary table
fprintf("\n========================================\n | %s FEA RESULTS
TABLE\n========================================\n\n", ... upper(selectedDesign));

========================================
DESIGN 1 FEA RESULTS TABLE ========================================

disp(feaResultsTable);

Material | MaximumDisplacement_mm | MaximumVonMisesStress_MPa | FactorOfSafety
_______________________________ | ______________________ | _________________________ | ______________
"Carbon Fiber Composite (CFRP)" | 0.059081 | 4.2484 | 141.23
"Aluminum Alloy" | 0.059894 | 4.2349 | 64.937
"Fiberglass Composite (GFRP)" | 0.1655 | 4.2546 | 70.512
"PLA Plastic" | 1.1798 | 4.2166 | 14.229
"ABS Plastic" | 2.0652 | 4.2232 | 9.4714
"Wood (Birch)" | 0.41304 | 4.2232 | 18.943

% Display FEA safety summary
fprintf("\n%s FEA Safety Summary:\n\nMaterials passing FEA requirements:\n", ... selectedDesign);

Design 1 FEA Safety Summary:

Materials passing FEA requirements:

feaPassed = false;

for i = 1:numberOfMaterials
if resultStatus(i) == "SAFE" fprintf(" %s\n", materialName(i)); feaPassed = true;
end
end

Carbon Fiber Composite (CFRP) Aluminum Alloy
Fiberglass Composite (GFRP) PLA Plastic
ABS Plastic
Wood (Birch)

if ~feaPassed
fprintf(" No materials passed\n");
end

fprintf("\nMaterials failing FEA requirements:\n");

Materials failing FEA requirements:

feaFailed = false;

for i = 1:numberOfMaterials
if resultStatus(i) == "UNSAFE" fprintf(" %s\n", materialName(i)); feaFailed = true;
end
end

if ~feaFailed
fprintf(" No materials failed\n"); end

No materials failed

## Task 5: Optimize the total material cost of the drone arm

Using the results from the thrust-to-weight analysis and finite element analysis, determine which material combination provides the lowest material cost while still meeting the required payload, thrust-to-weight ratio, and Factor of Safety.

Calculate the total material cost for each material option using the average material cost provided in the droneArmMaterials.mat file. Compare the valid material options and identify the option that provides the best balance of cost, performance, and structural safety.

% Number of materials
numberOfMaterials = length(materials);

% Initialize arrays
materialName = strings(numberOfMaterials, 1); totalMaterialCost = zeros(numberOfMaterials, 1); maximumPayload = zeros(numberOfMaterials, 1); factorOfSafety = zeros(numberOfMaterials, 1);

task3Status = strings(numberOfMaterials, 1); task4Status = strings(numberOfMaterials, 1); finalStatus = strings(numberOfMaterials, 1);

% Select design evaluated in Task 5

if selectedDesign == "Design 1"

armLength = 0.202;

elseif selectedDesign == "Design 2"

armLength = 0.251;

end

% Loop through materials
for materialNumber = 1:numberOfMaterials

materialName(materialNumber) = string(materials(materialNumber).name);

% Calculate total material cost for all four arms (rounded to the
% nearest cent)
totalMaterialCost(materialNumber) = round( ... materials(materialNumber).cost_USD_per_m ...
* armLength ...
* numberOfArms, 2);

% Find selected design result from Task 3
designIndex = ...
task3Results.designNames == selectedDesign & ... task3Results.materialNames == materialName(materialNumber);

% Store Task 3 numerical result
maximumPayload(materialNumber) = ... task3Results.maximumPayload(designIndex);

% Store Task 3 status internally task3Status(materialNumber) = ... task3Results.resultStatus(designIndex);

% Find material result from Task 4
materialIndex = ...
task4Results.materialNames == materialName(materialNumber);

% Store Task 4 numerical results factorOfSafety(materialNumber) = ... task4Results.factorOfSafety(materialIndex);

% Store Task 4 status internally task4Status(materialNumber) = ... task4Results.resultStatus(materialIndex);

% Final design decision requires both tasks to pass if task3Status(materialNumber) == "PASS" && ... task4Status(materialNumber) == "SAFE"

finalStatus(materialNumber) = "PASS";

else

finalStatus(materialNumber) = "FAIL";

end

end

% Create optimization summary table optimizationResults = table( ... materialName, ...
totalMaterialCost, ...
maximumPayload, ...
factorOfSafety, ...
'VariableNames', { ...
'Material', ...
'TotalMaterialCost_USD', ... 'MaximumPayload_kg', ...
'FactorOfSafety'});

% Plot cost comparison
figure;

barHandle = bar(totalMaterialCost);

plotColors = zeros(numberOfMaterials, 3);

for materialNumber = 1:numberOfMaterials

if finalStatus(materialNumber) == "PASS"

plotColors(materialNumber, :) = [0 0.7 0];

else

plotColors(materialNumber, :) = [0.9 0 0];

end

end

barHandle.FaceColor = "flat"; barHandle.CData = plotColors;

xticks(1:numberOfMaterials); xticklabels(materialName); xtickangle(45);

ylabel("Total Material Cost (USD)");

title(selectedDesign + " Material Cost Optimization Results");

grid on;

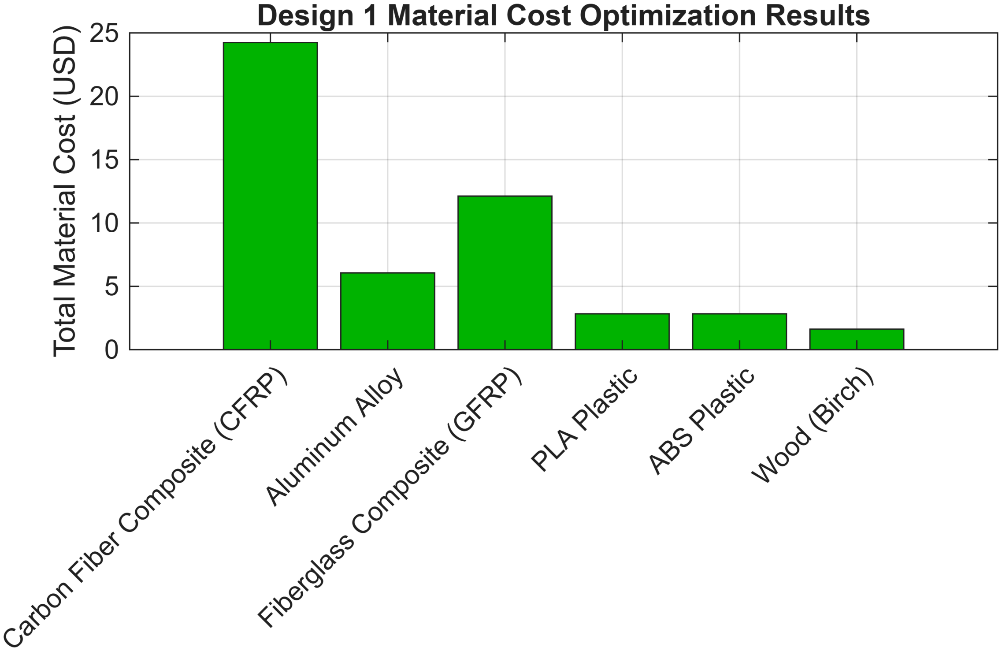
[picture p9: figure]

% Display numerical optimization results fprintf("\n========================================\n %s MATERIAL OPTIMIZATION TABLE\n========================================\n\n", ... upper(selectedDesign));

========================================
DESIGN 1 MATERIAL OPTIMIZATION TABLE ========================================

disp(optimizationResults);

Material | TotalMaterialCost_USD | MaximumPayload_kg | FactorOfSafety
_______________________________ | _____________________ | _________________ | ______________
"Carbon Fiber Composite (CFRP)" | 24.24 | 0.84107 | 141.23
"Aluminum Alloy" | 6.06 | 0.73181 | 64.937
"Fiberglass Composite (GFRP)" | 12.12 | 0.81128 | 70.512
"PLA Plastic" | 2.83 | 0.87584 | 14.229
"ABS Plastic" | 2.83 | 0.89571 | 9.4714
"Wood (Birch)" | 1.62 | 0.9404 | 18.943

% Find lowest cost material that satisfies all requirements
validOptions = optimizationResults(finalStatus == "PASS", :);

if isempty(validOptions)

fprintf("\nNo material option satisfies all required constraints.\n");

else

[lowestCost, lowestIndex] = min(validOptions.TotalMaterialCost_USD);

fprintf("\nLowest cost material satisfying all requirements:\nMaterial: %s\nMaterial Cost: %.2f USD\n", ...
validOptions.Material(lowestIndex), lowestCost);

end

Lowest cost material satisfying all requirements: Material: Wood (Birch)
Material Cost: 1.62 USD

## Interpretation of Results - Final Recommended Design Solution

Using the results of your thrust-to-weight analysis and finite element analysis, recommend a final drone arm design that meets all required constraints. Your recommendation should clearly identify the selected design (arm geometry and material choice), make use of quantitative results to justify your decisions, demonstrate that the design meets the constraints, explain the trade-offs considered, and include comparisons to alternative designs.

What are some limitations of your work?

What are practical next steps?

The final recommended drone arm design that meets all required constraints is Design 1, the hollow-tapered rectangular tube. The final recommended material choice for this design is Fiberglass Composite (GFRP). This recommendation was based not only on quantitative results, such as maximum payload capacity, maximum displacement, factor of safety (FoS), and cost, but also qualitative feasibility such as manufacturability and real-world material nuances that cannot be captured through this MATLAB analysis.

Before beginning the analysis, it is important to contextualize the geometry of both designs. Design 1 is a hollow-tapered rectangular tube structure that strategically allocates material where it is most needed. Since the arm experiences the highest bending loads near the connection point to the main drone body, Design 1 was designed with larger cross-sectional dimensions and thicker walls near the base while reducing material toward the motor mount, where less structural reinforcement is required. This approach allowed Design 1
to maintain the necessary structural capability while minimizing unnecessary material usage. In comparison, Design 2 uses a hollow truss-shaped internal structure intended to increase rigidity while reducing mass. However, a fundamental limitation was hypothesized (and later proved) to make it less effective: the horizontal orientation of the truss members made them less effective at resisting the dominant vertical bending loads generated by motor thrust. Therefore, prior to the analysis, it was surmised that Design 1 provided a more practical geometric solution.

The first constraint is that the design must support a minimum payload of 0.5 kg and achieve a thrust-to-weight ratio of at least 2:1 to ensure safe and stable flight. Given that the quadcopter has four motors, each producing one kilogram of thrust, the maximum allowable weight of the entire quadcopter is two kilograms. Since one kilogram is reserved for components of the drone other than the drone arms (i.e., frame, battery, motors, etc.), this leaves a weight budget of one kilogram for the remaining four drone arms and the minimum payload. Based on the drone design sketches and subsequent CAD volumes, it was determined that both designs successfully passed all the requirements. More importantly, the findings indicated that Design 1 had a smaller volume than Design 2, approximately 2.483207 × 10⁻⁵ m³ (24.83 cm³) compared to 3.4295614 × 10⁻⁵ m³ (34.30 cm³), and thus had less weight overall. This provided further indication that Design 1 was the better option, both because of its strategic use of geometry relative to the limitations identified in Design 2, and its better thrust-to-weight performance. As for the materials, GFRP used in Design 1 allowed for a maximum payload capacity of 0.81128 kilograms. However, this was not the highest-performing material in this respect, as CFRP, PLA, ABS, and Wood all produced higher maximum payload capacities of 0.84107 kg, 0.87584 kg, 0.89571 kg, and 0.94040 kg, respectively. Only Aluminum Alloy performed worse, producing a maximum payload capacity of 0.73181 kilograms.

The second requirement for the drone arm design was that the engineering safety margin, represented by the Factor of Safety (FoS), must be ~1.5-2+ under the given loading conditions of the motor applied to the motor mount face, while a separate face on the root attachment flange was fixed to represent the attachment point to the main drone body. Although this is a simplified representation of the actual loading conditions experienced during flight, it still produced meaningful results for comparing the structural performance of each material. All materials passed the required safety criteria. In particular, GFRP produced a maximum Von Mises stress of 4.2546 MPa, a maximum displacement of 0.1655 mm, and a Factor of Safety of 70.512. However, GFRP was still not the highest-performing option. CFRP produced the lowest maximum displacement of 0.059081 mm and the highest Factor of Safety of 141.23, while Aluminum Alloy produced a maximum displacement of 0.059894 mm and a Factor of Safety of 64.937. Wood produced a higher maximum displacement of 0.41304 mm and a Factor of Safety of 18.943. The largest concern appeared with the plastic materials, specifically PLA and ABS. While both materials technically passed the FoS requirement, PLA produced a maximum displacement of 1.1798 mm with a Factor of Safety of 14.229, and ABS produced
a maximum displacement of 2.0652 mm with a Factor of Safety of 9.4714. These displacement values
may seem reasonable, however, when compared to the actual wall thickness of Design 1, which tapers down to approximately 1.0 mm near the motor mount, the issue becomes apparent. The motor thrust can not be assumed to be aligned with the vertical loading direction because the displacement is greater than twice the thickness of the thinnest section of the arm. In real world conditions, such large deformation would introduce vibrations and dynamic instability, referred to in drone applications as the "jello effect." Although PLA and ABS satisfy the numerical FoS requirement, their excessive deformation makes them more likely to fail as material choices for this application.

Finally, a cost optimization was performed to determine which material satisfied all numerical requirements while minimizing the total material cost. Although GFRP resulted in a total material cost of $12.12, it
was not the least expensive option. Wood produced the lowest material cost at only $1.62, followed by PLA and ABS at $2.83, Aluminum Alloy at $6.06, GFRP at $12.12, and CFRP at $24.24. Based solely
on the numerical optimization, Wood would therefore be selected as the optimal material since it also achieved the highest maximum payload capacity of 0.94040 kg while maintaining a Factor of Safety of 18.943. However, this optimization does not capture several important real-world engineering considerations. Since Wood is a natural material, its mechanical properties are not consistent due to grain orientation, knots, moisture absorption, and manufacturing inconsistencies. Consequently, despite its excellent numerical performance and exceptionally low cost, Wood was not considered the most practical material for a drone arm. At the other end of the spectrum, CFRP provided the highest structural performance but was ultimately deemed unnecessary when GFRP produced similarly strong results for nearly half the cost. In conclusion, Design 1 manufactured from GFRP provides the most balanced engineering solution by satisfying all design requirements while meeting an effective balance between structural performance, manufacturing practicality, material consistency, and overall cost.

Several limitations should be considered when interpreting these results. The accuracy of the finite element analysis depends on mesh size; therefore, a reasonably refined mesh that demonstrated satisfactory convergence of the results was used, although a more comprehensive mesh convergence study with further refinement should be performed in future work. The FEA also only analyzed a single drone arm rather
than the complete drone assembly, meaning interactions between the arms, central frame, fasteners, and motor mounting hardware were not included. In addition, the material models assumed isotropic behavior, which simplifies the actual behavior of composite materials such as GFRP, whose properties depend on fiber orientation and manufacturing processes. The applied loading conditions were also simplified by representing the motor thrust and motor weight as a single surface traction, without accounting for real flight effects such as vibration, acceleration, impact loading, aerodynamic forces, or changing thrust conditions. The calculated Factor of Safety did not account for fatigue, manufacturing defects, environmental effects, or long-term material degradation.

For future steps, the drone assembly will be tested using more realistic loading conditions and material properties, while validating the numerical results through physical prototype testing.

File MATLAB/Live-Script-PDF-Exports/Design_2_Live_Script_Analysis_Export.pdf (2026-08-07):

## Drone Payload Structure Design and Analysis

In this project, you are optimizing drone arm design, including geometry and material selection, to maximize payload capacity while ensuring structural integrity under motor-induced loads. You will use MATLAB to perform force balance analysis and finite element modeling to quantitatively support your design solution.

Use this Live Script as a template to get started on your project solution. You may include helper functions at the bottom of this document or as separate files. For a tutorial on how to use Live Scripts, check out this video. (https://www.youtube.com/watch?v=hUXTyPYRidM)

Suggested Tasks

1. Gather your starter assumptions and load the material properties into MATLAB.
2. Propose at least two drone arm designs
3. Perform a thrust-to-weight analysis to evaluate each of your designs across all material options. Your design must meet a minimum payload requirement and safety standards.
4. Perform finite element analysis across all design and material options.
5. Recommend a final design solution.

Table of Contents

## Break Down the Problem

In the space below, define the problem statement:

The objective is to select a drone arm geometry and material combination that maximizes payload capacity while satisfying the minimum thrust-to-weight ratio and maintaining an acceptable structural safety factor under motor loading.

List the requirements, constraints, and success criteria for the project:

- The drone must support a minimum payload of 0.5 kg.
- The drone must meet a thrust-to-weight ratio of at least 2:1.
- The quadcopter configuration uses 4 motors and 4 propellers.
- Each motor can provide up to 1 kg of thrust.
- The total mass of the drone without arms or payload is 1 kg.
- The design must use at least two distinct arm geometries.
- The arm design must be evaluated across the available material options.
- The final selected design must satisfy the required payload and flight safety constraints.

- The structural design must maintain an acceptable factor of safety, with the target engineering range taken as approximately ~1.5-2+.
- Material cost should be considered as an optional optimization criterion in addition to the required performance and safety checks.

What is your proposed solution?

- The proposed solution is to compare two distinct drone arm geometries and evaluate them across the available material options using thrust-to-weight analysis and a single-arm finite element model to identify the combination that maximizes payload capacity while satisfying the required flight and structural safety constraints.

List the steps you will need to take to achieve your proposed solution:

1. Gather Starter Assumptions and Load Properties into MATLAB
2. Develop at Least Two Distinct Drone Arm Designs in CAD or by Hand
3. Write a MATLAB Function to Perform a Thrust-to-Weight Analysis Across All Design and Material Options
4. Create a 3D Model of One Drone Arm Using CAD Software of Your Choice
5. Import Your Model into MATLAB and Perform FEA
6. Report the Overall Maximum Displacement, Maximum Stress, and Factor of Safety for Each Design and Material Combination, Including Visualizations of the X-, Y-, and Z-Displacement and von Mises Stress
7. Recommend a Final Drone Arm Design That Meets All Required Constraints

What challenges do you face in the process of achieving the solution?

- The analysis is simplified to a single-arm structural model rather than the full four-arm drone assembly.
- Material properties are treated as homogeneous and isotropic, which is an approximation for composite and wood materials.
- The arm geometry and loading conditions are idealized rather than fully representing the complete flight environment.
- The FEA model captures only the dominant motor thrust and motor weight loading, while other real-world effects such as vibration, landing loads, and aerodynamic forces are not included.
- The design must balance payload capacity, structural stiffness, and material cost under the stated assumptions.

## Task 1: Gather your starter assumptions and load material properties

Load the provided droneArmMaterials.mat file into MATLAB. This contains a data struct with the material properties for six different materials commonly used for drones (carbon fiber composite, aluminum alloy, fiberglass composite, PLA plastic, ABS plastic, and wood). For each material, you have been provided the following information:

▪
Density ( ), in

- Young's Modulus (E) in Pa
- Poisson's ratio ( ), unitless
- Yield strength, in Pa
- Average cost per meter in US dollars

For this project, you can assume the following design parameters:

- Quadcopter drone with 4 motors and 4 propellers
- Each motor can provide up to 1kg thrust
▪
Acceleration due to gravity:
- Total weight of the drone components without the arms or the payload: 1kg

The breakdown of the weight of each drone component is as follow:

- Battery = 0.3kg
- Each motor = 65g, 4 motors = 0.26kg
- Each propeller = 10g, 4 propellers = 0.04 kg
- Each electronic speed controller = 30g, 4 electronic speed controllers = 0.12 kg
- Flight controller and electronics = 0.05kg
- Receiver/GPS = 0.03kg
- Drone frame (center body) excluding arms = 0.2kg

clc; clear; close all;

% Load material properties for the six drone arm materials load droneArmMaterials.mat;

% Define drone component masses (kg)
batteryMass = 0.30; % Battery
motorMass = 65 / 1000; % Each motor numberOfMotors = 4; % Number of motors totalMotorMass = motorMass * numberOfMotors;

propellerMass = 10 / 1000; % Each propeller
numberOfPropellers = 4; % Number of propellers
totalPropellerMass = propellerMass * numberOfPropellers;

speedControllerMass = 30 / 1000; % Each electronic speed controller numberOfSpeedControllers = 4; % Number of electronic speed controllers totalSpeedControllerMass = ...
speedControllerMass * numberOfSpeedControllers;

flightControllerMass = 0.05; % Flight controller and electronics receiverGPSMass = 0.03; % Receiver/GPS
droneFrameMass = 0.20; % Drone frame excluding arms

% Calculate total mass of the drone without arms or payload totalDroneMassWithoutArmsOrPayload = ...
batteryMass + ...
totalPropellerMass + ...
totalMotorMass + ...
totalSpeedControllerMass + ... flightControllerMass + ... receiverGPSMass + ...
droneFrameMass;

% Define general design parameters
gravity = 9.81; % Acceleration due to gravity (m/s^2) motorThrustCapacity = 1; % Maximum thrust per motor (kgf)
totalThrust = numberOfMotors * motorThrustCapacity;
minimumPayload = 0.5; % Minimum required payload (kg) requiredThrustToWeightRatio = 2; % Required thrust-to-weight ratio (2:1) numberOfArms = 4; % Number of arms on the quadcopter

## Task 2: Propose at least two drone arm designs

Develop at least two distinct drone arm designs by drawing clear, neatly labeled sketches that show key geometric features, including:

- Overall shape (e.g. beam, tube, truss structure)
- Dimensions (length, width, thickness)
- Motor mount location
- Where the arm connects to the drone body

The two designs should be meaningfully different from each other (e.g. different geometries or structural strategies) and not just small variations of the same idea.

Navigate to the 'Insert' tab and insert pictures of your sketches in the space below (hand-drawn or digital). Include a short design description for each sketch that includes:

- Geometry (e.g. solid beam, hollow tube, beam with trusses)
- Why you chose this design
- How it might perform under load

Note: All dimensions and measurements for the drone arm designs are provided in millimeters (mm) for consistency.

Drone Arm Design 1:


Geometry: A tapered hollow rectangular tube spanning a total length of 200.00 mm. The structure originates at the base with a 38.00 mm by 38.00 mm square attachment flange and a profile measuring 28.00 mm in width and 20.00 mm in height, featuring a wall thickness of 1.50 mm. It gracefully tapers toward the distal end to a profile measuring 28.00 mm in width and 10.00 mm in height, with a reduced wall thickness of 1.00 mm. The arm terminates in a 28.00 mm by 28.00 mm square motor mount platform positioned 2.00 mm above the top edge of the tapered body.

Reasoning: This geometry is chosen to optimize the strength-to-weight ratio. A drone arm acts as a cantilever beam, meaning the highest bending moments occur at the base where it attaches to the frame, while the stresses at the motor end are significantly lower. By tapering both the overall profile and the wall thickness, the design strategically places material only where it is needed to bear the load, stripping away unnecessary dead weight at the tip.

Analysis: Under the 1 kg upward thrust load, this arm is expected to show excellent bending stiffness at
the root, keeping overall deflections low. Because the tapered design minimizes the arm's total mass, it will consume less of the drone's 2 to 1 thrust-to-weight budget, maximizing the remaining capacity available to safely carry the required 0.5 kg payload.

Drone Arm Design 2:


Geometry: A hollow, truss-shaped interior where each truss arm or branch has a thickness of approximately 2.0370 mm. The outside walls feature a continuous inward curve (with a radius of 189.2582 mm), causing the internal truss structure to narrow towards the middle before widening again as it approaches the motor housing. Holes for the arm connection are placed in a triangle shape. The total height of the drone arm is 7.493 mm throughout.

Reasoning: Truss shapes of the inside part of the drone arm are designed for stabilization, optimal strength, material efficiency, and weight reduction. This drone arm design also allows for creativity of the user or any future re-designers regarding the placement of the motor. The arm connection to the body of the drone is also shaped in a triangle to ensure the placement is optimally secured and geometrically rigid.

Analysis: While the truss structure of the drone arm design will provide strength and stiffness, the region between the arm connection and the starting portion of where the curvature begins might cause future problems; further optimization might be required in order to avoid a snap of that region.

## Task 3: Perform thrust-to-weight analysis across all design and material options

Write a MATLAB function that will perform a thrust-to-weight analysis across all design and material options. This analysis will help you evaluate which drone arm design and which material optimizes payload capacity while meeting suggested safety requirements.

- Your design must support a minimum payload of 0.5kg.
- Your design must meet a thrust-to-weight ratio of at least 2:1 to ensure safe and stable flight. This safety standard is widely used in drone design. Conceptually, it means that the drone's maximum thrust must be at least twice its weight. This ensures stable hovering and maneuvering with a safety margin. Note that the thrust-to-weight safety margin is a system-level safety standard for drone flight that is distinct from the structural safety factor of the drone arms (which you will evaluate later through finite element analysis).
- Your goal is calculate maximum payload capacity for each design and material option (i.e. what is the heaviest payload your drone design could carry while still allowing the drone to safely take off?)

Ensure that the results of your analysis can be readily interpreted, e.g. in the form of a summary table or plot.

Note: if you have two drone arm designs, the expected output should be 12 payload capacity estimates (2 designs across 6 materials options).

% Define arm volumes from Task 2
armVolume1 = 2.483207e-5;
armVolume2 = 3.4295614e-5;

% Store both design volumes for comparison armVolumes = [armVolume1, armVolume2];

% Define names for each drone arm design
designNames = ["Design 1", "Design 2"];

% Perform thrust-to-weight analysis for all designs and materials task3Results = thrustToWeightAnalysis( ...
armVolumes, ...
designNames, ...
materials, ...
totalDroneMassWithoutArmsOrPayload, ... totalThrust, ...
minimumPayload, ...
requiredThrustToWeightRatio, ... numberOfArms);


======================================== DESIGN 1 MAXIMUM PAYLOAD TABLE ========================================

Material | TotalArmMass_kg | MaximumPayload_kg
_______________________________ | _______________ | _________________
"Carbon Fiber Composite (CFRP)" | 0.15893 | 0.84107
"Aluminum Alloy" | 0.26819 | 0.73181
"Fiberglass Composite (GFRP)" | 0.18872 | 0.81128
"PLA Plastic" | 0.12416 | 0.87584
"ABS Plastic" | 0.10429 | 0.89571
"Wood (Birch)" | 0.059597 | 0.9404

Design 1 Maximum Payload Summary:

Design 1 Passes for:
Carbon Fiber Composite (CFRP) Aluminum Alloy
Fiberglass Composite (GFRP) PLA Plastic
ABS Plastic
Wood (Birch)

Design 1 Fails for:
No materials failed

======================================== DESIGN 2 MAXIMUM PAYLOAD TABLE ========================================

Material | TotalArmMass_kg | MaximumPayload_kg
_______________________________ | _______________ | _________________
"Carbon Fiber Composite (CFRP)" | 0.21949 | 0.78051
"Aluminum Alloy" | 0.37039 | 0.62961
"Fiberglass Composite (GFRP)" | 0.26065 | 0.73935
"PLA Plastic" | 0.17148 | 0.82852
"ABS Plastic" | 0.14404 | 0.85596
"Wood (Birch)" | 0.082309 | 0.91769

Design 2 Maximum Payload Summary:

Design 2 Passes for:
Carbon Fiber Composite (CFRP) Aluminum Alloy
Fiberglass Composite (GFRP) PLA Plastic
ABS Plastic
Wood (Birch)

Design 2 Fails for:
No materials failed

function task3Results = thrustToWeightAnalysis( ... armVolumes, designNames, materials, ... totalDroneMassWithoutArmsOrPayload, ... totalThrust, minimumPayload, ...
requiredThrustToWeightRatio, ...
numberOfArms)

% Determine the number of materials and design-material combinations numberOfMaterials = length(materials);
numberOfCombinations = length(armVolumes) * numberOfMaterials;

% Initialize arrays for storing analysis results
designNameResults = strings(numberOfCombinations, 1); materialNameResults = strings(numberOfCombinations, 1); armDensity = zeros(numberOfCombinations, 1); totalArmMass = zeros(numberOfCombinations, 1); maximumPayload = zeros(numberOfCombinations, 1); resultStatus = strings(numberOfCombinations, 1);

% Calculate the maximum allowable drone mass based on the required thrust-to-weight ratio
maximumAllowedTotalMass = totalThrust / requiredThrustToWeightRatio;

% Initialize combination counter
combinationNumber = 1;

% Loop through each arm design
for designNumber = 1:length(armVolumes)

% Get the current arm volume currentArmVolume = armVolumes(designNumber);

% Loop through each material option
for materialNumber = 1:numberOfMaterials

% Store current design and material information designNameResults(combinationNumber) = designNames(designNumber); materialNameResults(combinationNumber) = string(materials(materialNumber).name); armDensity(combinationNumber) = materials(materialNumber).rho_kg_m3;

% Calculate the total mass of all four drone arms totalArmMass(combinationNumber) = ...
currentArmVolume * armDensity(combinationNumber) * numberOfArms;

% Calculate the maximum payload capacity for the current design-material combination
maximumPayload(combinationNumber) = ...
maximumAllowedTotalMass - ... totalDroneMassWithoutArmsOrPayload - ... totalArmMass(combinationNumber);

% Calculate the total drone mass including the minimum payload totalDroneMass = ...
totalDroneMassWithoutArmsOrPayload ...
+ totalArmMass(combinationNumber) ...
+ minimumPayload;

% Check if the design satisfies payload and thrust-to-weight requirements
if maximumPayload(combinationNumber) >= minimumPayload && ... totalThrust / totalDroneMass >= requiredThrustToWeightRatio

resultStatus(combinationNumber) = "PASS";

else

resultStatus(combinationNumber) = "FAIL";

end

% Move to the next design-material combination combinationNumber = combinationNumber + 1;

end
end

% Create a complete table containing all internal analysis results fullTable = table( ...
designNameResults, ...
materialNameResults, ...
armDensity, ...
totalArmMass, ...
maximumPayload, ...
'VariableNames', { ...
'Design', ...
'Material', ...
'Density_kg_m3', ...
'TotalArmMass_kg', ...
'MaximumPayload_kg'});

% Save internal results for later use in Task 5 task3Results.designNames = designNameResults; task3Results.materialNames = materialNameResults; task3Results.maximumPayload = maximumPayload; task3Results.resultStatus = resultStatus;

% Extract display tables for each individual design design1Display = fullTable( ...
fullTable.Design == "Design 1", ...
{'Material', 'TotalArmMass_kg', 'MaximumPayload_kg'}); design2Display = fullTable( ...
fullTable.Design == "Design 2", ...
{'Material', 'TotalArmMass_kg', 'MaximumPayload_kg'});

% Create a payload comparison plot for each design
for designNumber = 1:length(designNames)

% Create a new figure for the current design
figure;

% Identify results belonging to the current design designIndex = designNameResults == designNames(designNumber); designPayload = maximumPayload(designIndex);
designStatus = resultStatus(designIndex);
designMaterials = materialNameResults(designIndex);

% Create bar plot of maximum payload capacity barHandle = bar(designPayload);

% Initialize colors based on pass or fail status
plotColors = zeros(numberOfMaterials, 3);

% Assign green to passing materials and red to failing materials for materialNumber = 1:numberOfMaterials

if designStatus(materialNumber) == "PASS" plotColors(materialNumber, :) = [0 0.7 0];

else
plotColors(materialNumber, :) = [0.9 0 0];

end

end

% Apply colors to the bar chart barHandle.FaceColor = "flat"; barHandle.CData = plotColors;

% Format x-axis labels
xticks(1:numberOfMaterials); xticklabels(designMaterials); xtickangle(45);

% Add plot labels and title
ylabel("Maximum Payload (kg)"); title(designNames(designNumber) + " Maximum Payload Capacity");

% Display minimum payload requirement
yline(minimumPayload, "--", "Minimum Payload", ...
"Color", [1 0.1 0.7], "LineWidth", 3);

% Set plot limits and enable grid
ylim([0 1]);
yticks(0:0.2:1);
grid on;

end

% Display Design 1 results
fprintf("\n");
fprintf("========================================\n"); fprintf(" DESIGN 1 MAXIMUM PAYLOAD TABLE\n"); fprintf("========================================\n\n"); disp(design1Display);

% Design 1 Summary:

fprintf("\nDesign 1 Maximum Payload Summary:\n");

design1Payload = maximumPayload(1:numberOfMaterials); design1Materials = materialNameResults(1:numberOfMaterials);

% Design 1 passes
fprintf("\nDesign 1 Passes for:\n");

design1Passed = false;

for i = 1:numberOfMaterials
if design1Payload(i) >= minimumPayload fprintf(" %s\n", design1Materials(i)); design1Passed = true;
end
end

if ~design1Passed
fprintf(" No materials passed\n"); end

% Design 1 fails
fprintf("\nDesign 1 Fails for:\n");

design1Failed = false;

for i = 1:numberOfMaterials
if design1Payload(i) < minimumPayload fprintf(" %s\n", design1Materials(i)); design1Failed = true;
end
end

if ~design1Failed
fprintf(" No materials failed\n"); end

% Display Design 2 results
fprintf("\n");
fprintf("========================================\n"); fprintf(" DESIGN 2 MAXIMUM PAYLOAD TABLE\n"); fprintf("========================================\n\n"); disp(design2Display);

% Design 2 Summary:
fprintf("\nDesign 2 Maximum Payload Summary:\n");

design2Payload = maximumPayload(numberOfMaterials+1:2*numberOfMaterials); design2Materials = materialNameResults(numberOfMaterials+1:2*numberOfMaterials);

% Design 2 passes
fprintf("\nDesign 2 Passes for:\n");

design2Passed = false;

for i = 1:numberOfMaterials
if design2Payload(i) >= minimumPayload fprintf(" %s\n", design2Materials(i)); design2Passed = true;
end
end

if ~design2Passed
fprintf(" No materials passed\n"); end

% Design 2 fails
fprintf("\nDesign 2 Fails for:\n");

design2Failed = false;

for i = 1:numberOfMaterials
if design2Payload(i) < minimumPayload fprintf(" %s\n", design2Materials(i)); design2Failed = true;
end
end

if ~design2Failed
fprintf(" No materials failed\n"); end
end

## Task 4: Perform finite element analysis across all design and material options

Perform finite element analysis (FEA) across all design and material options to evaluate the structural safety factor of your drone arm design. To simplify the task, you will perform the FEA only on a single drone arm.

Using a CAD software of your choice, first create a 3D model of one drone arm for each of your designs. Be sure your model can be exported as a STEP or STL file for analysis in MATLAB.

- Recommended CAD software options: Tinkercad, Onshape, Fusion 360, Solidworks (most have free versions)

Import your model into MATLAB and perform FEA. In your FEA model, you should model and apply two loads to the drone arm: upward thrust force from the motor and downward weight of the motor.

- Helpful resources: online tutorial, (https://matlabacademy.mathworks.com/details/introduction-to-finite-element-analysis-with-matlab/otmlfea) documentation for Structural Mechanics (https://www.mathworks.com/help/pde/structural-mechanics.html) and Partial Differentiation Equation Toolbox, (https://www.mathworks.com/help/pde/index.html?s_tid=CRUX_lftnav) and example workflow (https://www.mathworks.com/help/pde/ug/deflection-analysis-of-bracket-femodel.html)

For the chosen design and each material combination, you should report the overall maximum displacement, maximum stress, and factor of safety and include visualizations of the x-, y-, and z-displacement and Von
Mises stress. Ensure that your results are presented for easy interpretation (e.g. present a table with numerical results, clearly labeled subplots for the visualizations).
- The factor of safety compares how strong a material is to how much stress it experiences, indicating whether
a design is safe under the given loads. For this project use the equation: | .

Yield strength indicates how much stress a given material can withstand before permanently deforming. Maximum von Mises stress (derived from your FEA model) is a measure of how much stress your design experiences under the applied loads.
- A typical engineering safety margin for FoS is ~1.5-2+
- This example (https://www.mathworks.com/help/pde/ug/deflection-analysis-of-bracket-femodel.html) demonstrates the plots you are asked to include in your results

% STEP 1: Import drone arm geometry into MATLAB, visualize the geometry to % identify key faces (e.g. tip face)

% Select which drone arm design to analyze.
% By default, Design 1 will run.
% To run Design 2, comment out the first line below and uncomment the second.
% Ensure the corresponding CAD file is in the same directory as this Live Script. % selectedDesign = "Design 1";
selectedDesign = "Design 2";

if selectedDesign == "Design 1"

CADfile = "Design_1_CAD_Model.STEP"; fixedFaceID = 24;
motorMountFaceID = 33;
motorMountFaceArea = 0.00062144;

elseif selectedDesign == "Design 2"

CADfile = "Design_2_CAD_Model.STL"; fixedFaceID = 111;
motorMountFaceID = 82;
motorMountFaceArea = 0.000866359;

end

% Initialize the finite element model using the geometry
modelFE = femodel(AnalysisType="structuralStatic", Geometry=CADfile);

% Apply STL scaling only for Design 2
if selectedDesign == "Design 2"
modelFE.Geometry = scale(modelFE.Geometry,0.001); end

% Generate the finite element mesh
modelFE = generateMesh(modelFE, Hmax=1.5e-3);

% Plot the geometry and display face labels
% This allows the fixed base and motor mount faces to be identified figure;

pdegplot(modelFE, FaceLabels="on", FaceAlpha=0.5);

view(30, 30);
axis equal;
title(selectedDesign + " Drone Arm Face Labels");

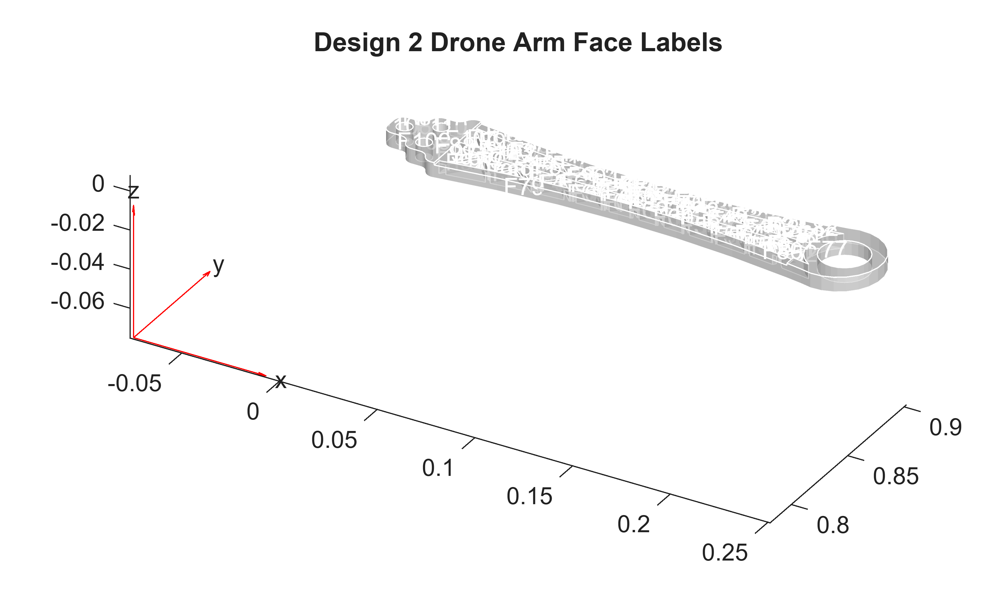
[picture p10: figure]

% IMPORTANT:
% Visually confirm from this face-label plot that the selected face IDs % correspond to the intended physical locations

% STEP 2: Define material properties

% Get the number of available materials
numberOfMaterials = length(materials);

% Initialize arrays for storing FEA results for all six materials materialName = strings(numberOfMaterials, 1);

maximumDisplacementResults = zeros(numberOfMaterials, 1); maximumVonMisesStressResults = zeros(numberOfMaterials, 1); factorOfSafetyResults = zeros(numberOfMaterials, 1);
resultStatus = strings(numberOfMaterials, 1);

% STEP 3: Apply boundary conditions (fix base of arm where it would be % attached to drone body)

modelFE.FaceBC(fixedFaceID) = ...
faceBC(Constraint="fixed");

% STEP 4: Apply the upward thrust force (motor force)
% Define the thrust force, convert force to surface traction, apply
% surface traction to the appropriate face in the appropriate direction

% Calculate the upward thrust force from the motor
motorThrustForce_N = motorThrustCapacity * gravity;

% STEP 5: Apply downward motor weight
% Define motor weight, convert to traction, apply to the appropriate face % in the appropriate direction

% Calculate the downward weight of the motor
motorWeightForce_N = motorMass * gravity;

% Calculate the net force acting in the loading direction
% The upward motor thrust is positive and the downward motor weight is % negative
netForceZ_N = motorThrustForce_N - motorWeightForce_N;

% IMPORTANT:
% SurfaceTraction is specified in the global Cartesian coordinate system % The current model assumes that positive global Z is the upward thrust % direction based on the STEP model coordinate orientation

thrustDirection = [0; 0; 1];

% Calculate the net surface traction
netTractionMagnitude = netForceZ_N / motorMountFaceArea;

% Convert the scalar net traction into a global Cartesian vector netTraction = thrustDirection * netTractionMagnitude;

% Apply the combined net traction to the motor mount face modelFE.FaceLoad(motorMountFaceID) = faceLoad(SurfaceTraction=netTraction);

% STEP 6: Solve the FEA model for materialNumber = 1:numberOfMaterials

% Print the current material being processed
fprintf("Running FEA for material %d/%d: %s\n", ...
materialNumber, numberOfMaterials, string(materials(materialNumber).name)); drawnow;

% Get material information from the droneArmMaterials data structure materialName(materialNumber) = string(materials(materialNumber).name);

YoungsModulus = materials(materialNumber).E_Pa;
PoissonsRatio = materials(materialNumber).nu;
YieldStrength = materials(materialNumber).yieldStrength_Pa;

% Assign material properties to the finite element model currentModel = modelFE;

currentModel.MaterialProperties = materialProperties( ... YoungsModulus=YoungsModulus, ... PoissonsRatio=PoissonsRatio);

% Solve the FEA model for the current material
results = solve(currentModel);

% STEP 7: Get numerical results

% Calculate displacement magnitude at every mesh node displacementMagnitude = sqrt( ... results.Displacement.ux.^2 + ... results.Displacement.uy.^2 + ... results.Displacement.uz.^2);

% Calculate the maximum displacement magnitude maximumDisplacement = max(displacementMagnitude);

% Calculate the maximum Von Mises stress maximumVonMisesStress = max(results.VonMisesStress);

% Calculate the factor of safety
factorOfSafety = YieldStrength / maximumVonMisesStress;

% Store numerical results (conversion of units) maximumDisplacementResults(materialNumber) = maximumDisplacement * 1000; maximumVonMisesStressResults(materialNumber) = maximumVonMisesStress / 1e6; factorOfSafetyResults(materialNumber) = factorOfSafety;

% Determine whether the design meets the recommended
% minimum factor of safety of 1.5
if factorOfSafety >= 1.5 resultStatus(materialNumber) = "SAFE"; else
resultStatus(materialNumber) = "UNSAFE"; end

% STEP 8: Visualize your results
figure;
sgtitle(selectedDesign + " - " + materialName(materialNumber) + " FEA Results");

subplot(2,2,1);
pdeplot3D(results.Mesh, ColorMapData=results.Displacement.ux);
title("X Displacement");
xlabel("X");
ylabel("Y");
zlabel("Z");
axis equal;
colormap(gca, "jet");
colorbar;

subplot(2,2,2);
pdeplot3D(results.Mesh, ColorMapData=results.Displacement.uy); title("Y Displacement");
xlabel("X");
ylabel("Y");
zlabel("Z");
axis equal;
colormap(gca, "jet");
colorbar;

subplot(2,2,3);
pdeplot3D(results.Mesh, ColorMapData=results.Displacement.uz); title("Z Displacement");
xlabel("X");
ylabel("Y");
zlabel("Z");
axis equal;
colormap(gca, "jet");
colorbar;

subplot(2,2,4);
pdeplot3D(results.Mesh, ColorMapData=results.VonMisesStress); title("Von Mises Stress");
xlabel("X");
ylabel("Y");
zlabel("Z");
axis equal;
colormap(gca, "jet");
colorbar;

end

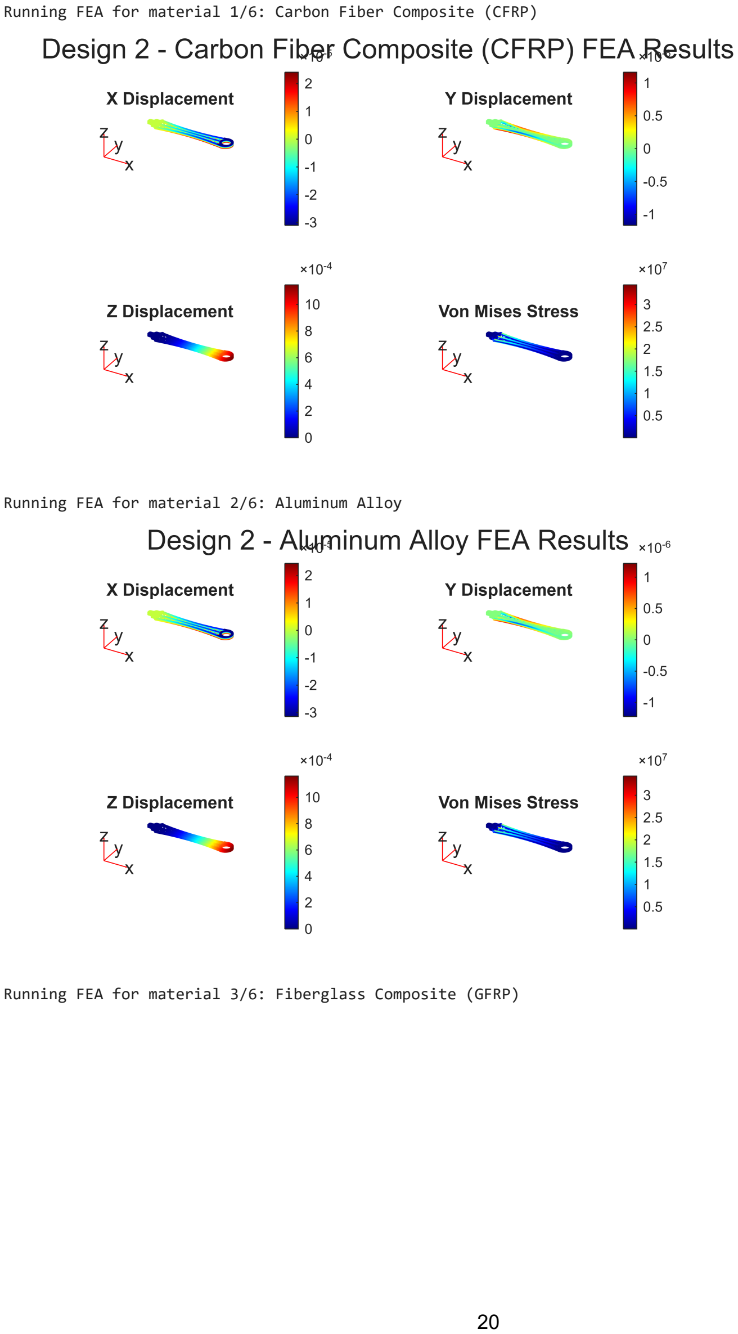
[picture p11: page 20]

Running FEA for material 1/6: Carbon Fiber Composite (CFRP)

Running FEA for material 2/6: Aluminum Alloy

Running FEA for material 3/6: Fiberglass Composite (GFRP)

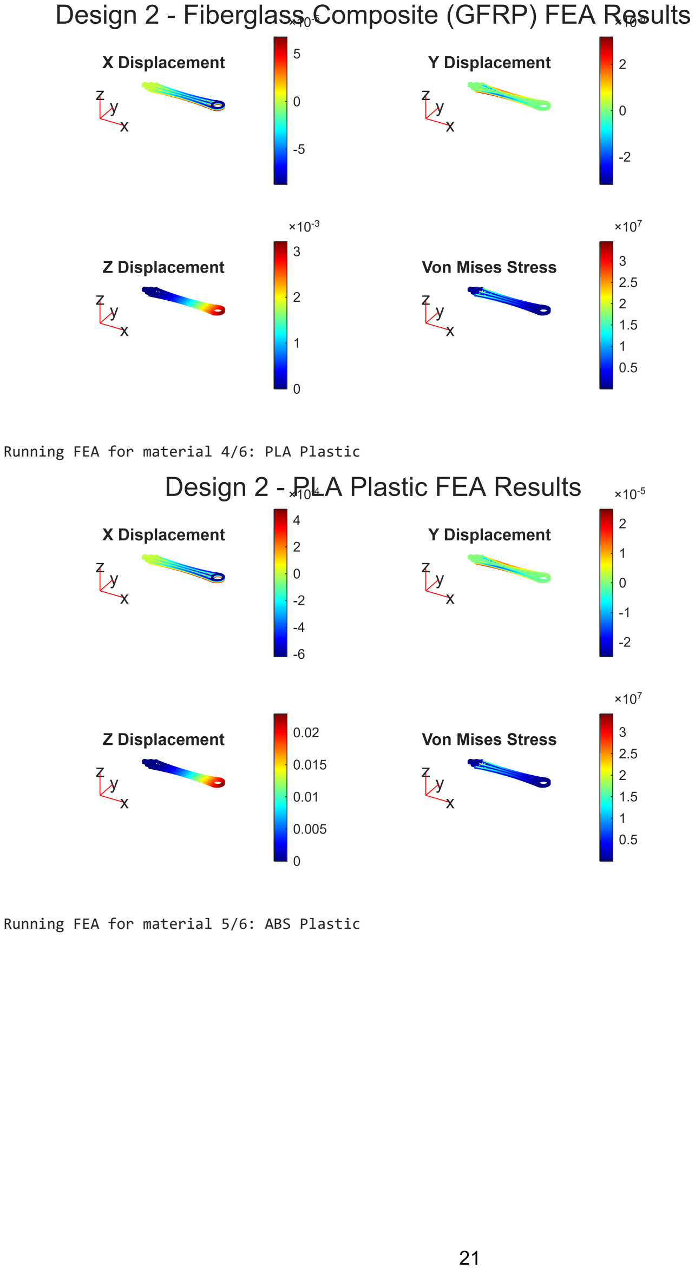
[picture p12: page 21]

Running FEA for material 4/6: PLA Plastic

Running FEA for material 5/6: ABS Plastic

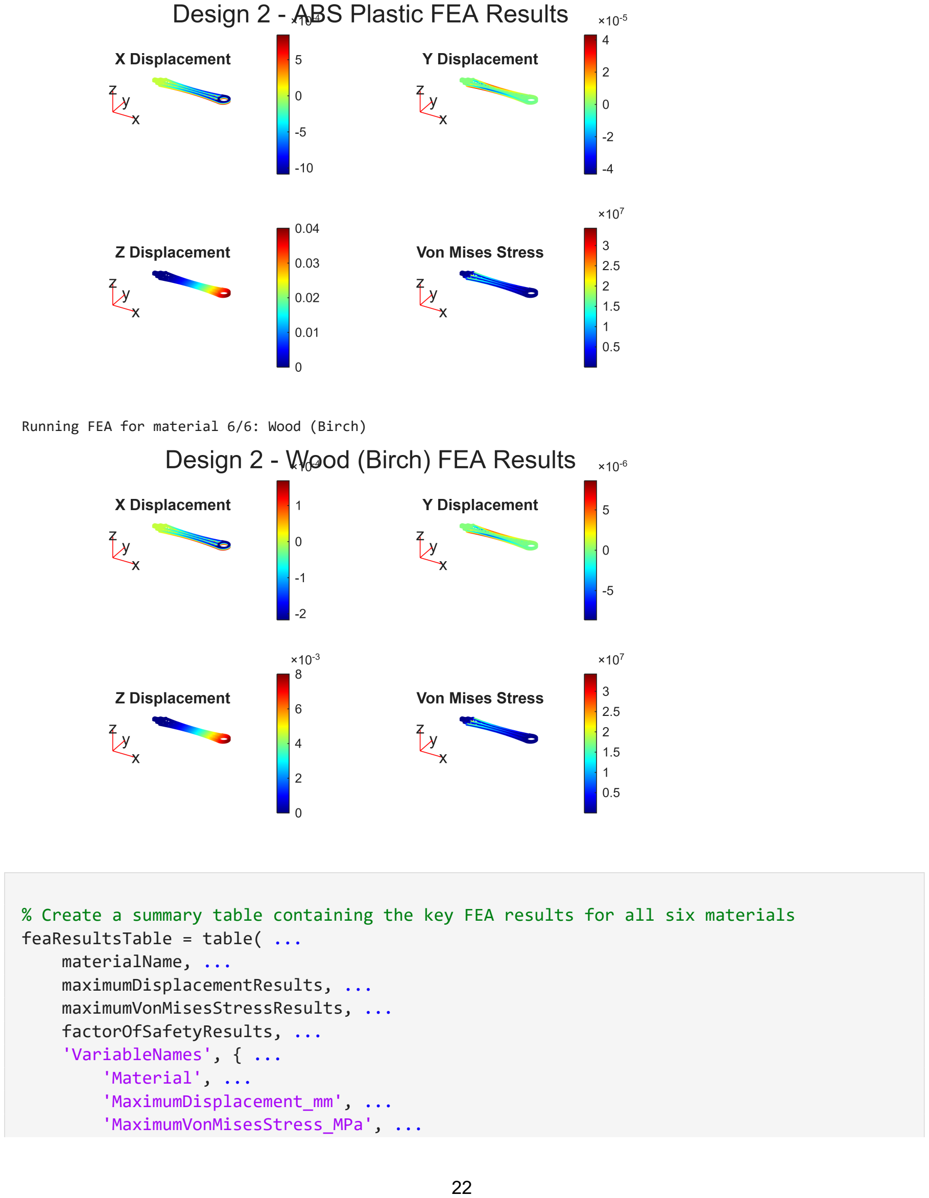
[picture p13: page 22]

Running FEA for material 6/6: Wood (Birch)

% Create a summary table containing the key FEA results for all six materials feaResultsTable = table( ...
materialName, ...
maximumDisplacementResults, ...
maximumVonMisesStressResults, ... factorOfSafetyResults, ... 'VariableNames', { ...
'Material', ...
'MaximumDisplacement_mm', ... 'MaximumVonMisesStress_MPa', ...

'FactorOfSafety'});

% Save complete internal results for later use in Task 5 task4Results.materialNames = materialName; task4Results.factorOfSafety = factorOfSafetyResults; task4Results.resultStatus = resultStatus;

% Display the FEA summary table
fprintf("\n========================================\n | %s FEA RESULTS
TABLE\n========================================\n\n", ... upper(selectedDesign));

========================================
DESIGN 2 FEA RESULTS TABLE ========================================

disp(feaResultsTable);

Material | MaximumDisplacement_mm | MaximumVonMisesStress_MPa | FactorOfSafety
_______________________________ | ______________________ | _________________________ | ______________
"Carbon Fiber Composite (CFRP)" | 1.1464 | 34.414 | 17.435
"Aluminum Alloy" | 1.1621 | 34.31 | 8.0151
"Fiberglass Composite (GFRP)" | 3.2112 | 34.501 | 8.6954
"PLA Plastic" | 22.889 | 34.244 | 1.7522
"ABS Plastic" | 40.068 | 34.261 | 1.1675
"Wood (Birch)" | 8.0137 | 34.261 | 2.335

% Display FEA safety summary
fprintf("\n%s FEA Safety Summary:\n\nMaterials passing FEA requirements:\n", ... selectedDesign);

Design 2 FEA Safety Summary:

Materials passing FEA requirements:

feaPassed = false;

for i = 1:numberOfMaterials
if resultStatus(i) == "SAFE" fprintf(" %s\n", materialName(i)); feaPassed = true;
end
end

Carbon Fiber Composite (CFRP) Aluminum Alloy
Fiberglass Composite (GFRP) PLA Plastic
Wood (Birch)

if ~feaPassed
fprintf(" No materials passed\n");
end

fprintf("\nMaterials failing FEA requirements:\n");

Materials failing FEA requirements:

feaFailed = false;

for i = 1:numberOfMaterials
if resultStatus(i) == "UNSAFE" fprintf(" %s\n", materialName(i)); feaFailed = true;
end
end

ABS Plastic

if ~feaFailed
fprintf(" No materials failed\n");
end

## Task 5: Optimize the total material cost of the drone arm

Using the results from the thrust-to-weight analysis and finite element analysis, determine which material combination provides the lowest material cost while still meeting the required payload, thrust-to-weight ratio, and Factor of Safety.

Calculate the total material cost for each material option using the average material cost provided in the droneArmMaterials.mat file. Compare the valid material options and identify the option that provides the best balance of cost, performance, and structural safety.

% Number of materials
numberOfMaterials = length(materials);

% Initialize arrays
materialName = strings(numberOfMaterials, 1); totalMaterialCost = zeros(numberOfMaterials, 1); maximumPayload = zeros(numberOfMaterials, 1); factorOfSafety = zeros(numberOfMaterials, 1);

task3Status = strings(numberOfMaterials, 1); task4Status = strings(numberOfMaterials, 1); finalStatus = strings(numberOfMaterials, 1);

% Select design evaluated in Task 5

if selectedDesign == "Design 1"

armLength = 0.202;

elseif selectedDesign == "Design 2"

armLength = 0.251;

end

% Loop through materials
for materialNumber = 1:numberOfMaterials

materialName(materialNumber) = string(materials(materialNumber).name);

% Calculate total material cost for all four arms (rounded to the
% nearest cent)
totalMaterialCost(materialNumber) = round( ... materials(materialNumber).cost_USD_per_m ...
* armLength ...
* numberOfArms, 2);

% Find selected design result from Task 3
designIndex = ...
task3Results.designNames == selectedDesign & ... task3Results.materialNames == materialName(materialNumber);

% Store Task 3 numerical result
maximumPayload(materialNumber) = ... task3Results.maximumPayload(designIndex);

% Store Task 3 status internally task3Status(materialNumber) = ... task3Results.resultStatus(designIndex);

% Find material result from Task 4
materialIndex = ...
task4Results.materialNames == materialName(materialNumber);

% Store Task 4 numerical results factorOfSafety(materialNumber) = ... task4Results.factorOfSafety(materialIndex);

% Store Task 4 status internally task4Status(materialNumber) = ... task4Results.resultStatus(materialIndex);

% Final design decision requires both tasks to pass if task3Status(materialNumber) == "PASS" && ... task4Status(materialNumber) == "SAFE"

finalStatus(materialNumber) = "PASS";

else

finalStatus(materialNumber) = "FAIL";

end

end

% Create optimization summary table optimizationResults = table( ... materialName, ...
totalMaterialCost, ...
maximumPayload, ...
factorOfSafety, ...
'VariableNames', { ...
'Material', ...
'TotalMaterialCost_USD', ... 'MaximumPayload_kg', ...
'FactorOfSafety'});

% Plot cost comparison
figure;

barHandle = bar(totalMaterialCost);

plotColors = zeros(numberOfMaterials, 3);

for materialNumber = 1:numberOfMaterials

if finalStatus(materialNumber) == "PASS"

plotColors(materialNumber, :) = [0 0.7 0];

else

plotColors(materialNumber, :) = [0.9 0 0];

end

end

barHandle.FaceColor = "flat"; barHandle.CData = plotColors;

xticks(1:numberOfMaterials); xticklabels(materialName); xtickangle(45);

ylabel("Total Material Cost (USD)");
title(selectedDesign + " Material Cost Optimization Results");

grid on;

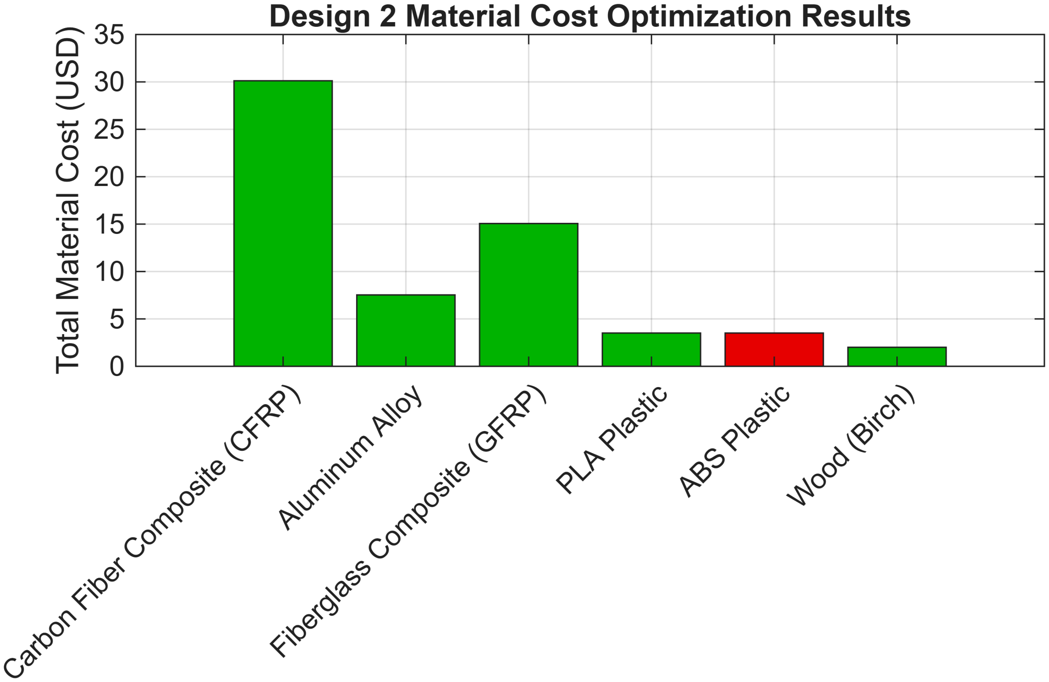
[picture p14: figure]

% Display numerical optimization results fprintf("\n========================================\n %s MATERIAL OPTIMIZATION TABLE\n========================================\n\n", ... upper(selectedDesign));

========================================
DESIGN 2 MATERIAL OPTIMIZATION TABLE ========================================

disp(optimizationResults);

Material | TotalMaterialCost_USD | MaximumPayload_kg | FactorOfSafety
_______________________________ | _____________________ | _________________ | ______________
"Carbon Fiber Composite (CFRP)" | 30.12 | 0.78051 | 17.435
"Aluminum Alloy" | 7.53 | 0.62961 | 8.0151
"Fiberglass Composite (GFRP)" | 15.06 | 0.73935 | 8.6954
"PLA Plastic" | 3.51 | 0.82852 | 1.7522
"ABS Plastic" | 3.51 | 0.85596 | 1.1675
"Wood (Birch)" | 2.01 | 0.91769 | 2.335

% Find lowest cost material that satisfies all requirements
validOptions = optimizationResults(finalStatus == "PASS", :);

if isempty(validOptions)

fprintf("\nNo material option satisfies all required constraints.\n");

else

[lowestCost, lowestIndex] = min(validOptions.TotalMaterialCost_USD);

fprintf("\nLowest cost material satisfying all requirements:\nMaterial: %s\nMaterial Cost: %.2f USD\n", ...
validOptions.Material(lowestIndex), lowestCost);

end

Lowest cost material satisfying all requirements: Material: Wood (Birch)
Material Cost: 2.01 USD

## Interpretation of Results - Final Recommended Design Solution

Using the results of your thrust-to-weight analysis and finite element analysis, recommend a final drone arm design that meets all required constraints. Your recommendation should clearly identify the selected design (arm geometry and material choice), make use of quantitative results to justify your decisions, demonstrate that the design meets the constraints, explain the trade-offs considered, and include comparisons to alternative designs.

What are some limitations of your work?

What are practical next steps?

The final recommended drone arm design that meets all required constraints is Design 1, the hollow-tapered rectangular tube. The final recommended material choice for this design is Fiberglass Composite (GFRP). This recommendation was based not only on quantitative results, such as maximum payload capacity, maximum displacement, factor of safety (FoS), and cost, but also qualitative feasibility such as manufacturability and real-world material nuances that cannot be captured through this MATLAB analysis.

Before beginning the analysis, it is important to contextualize the geometry of both designs. Design 1 is a hollow-tapered rectangular tube structure that strategically allocates material where it is most needed. Since the arm experiences the highest bending loads near the connection point to the main drone body, Design 1 was designed with larger cross-sectional dimensions and thicker walls near the base while reducing material toward the motor mount, where less structural reinforcement is required. This approach allowed Design 1
to maintain the necessary structural capability while minimizing unnecessary material usage. In comparison, Design 2 uses a hollow truss-shaped internal structure intended to increase rigidity while reducing mass. However, a fundamental limitation was hypothesized (and later proved) to make it less effective: the horizontal orientation of the truss members made them less effective at resisting the dominant vertical bending loads generated by motor thrust. Therefore, prior to the analysis, it was surmised that Design 1 provided a more practical geometric solution.

The first constraint is that the design must support a minimum payload of 0.5 kg and achieve a thrust-to-weight ratio of at least 2:1 to ensure safe and stable flight. Given that the quadcopter has four motors, each producing one kilogram of thrust, the maximum allowable weight of the entire quadcopter is two kilograms. Since one kilogram is reserved for components of the drone other than the drone arms (i.e., frame, battery, motors, etc.), this leaves a weight budget of one kilogram for the remaining four drone arms and the minimum payload. Based on the drone design sketches and subsequent CAD volumes, it was determined that both designs successfully passed all the requirements. More importantly, the findings indicated that Design 1 had a smaller volume than Design 2, approximately 2.483207 × 10⁻⁵ m³ (24.83 cm³) compared to 3.4295614 × 10⁻⁵ m³ (34.30 cm³), and thus had less weight overall. This provided further indication that Design 1 was the better option, both because of its strategic use of geometry relative to the limitations identified in Design 2, and its better thrust-to-weight performance. As for the materials, GFRP used in Design 1 allowed for a maximum payload capacity of 0.81128 kilograms. However, this was not the highest-performing material in this respect, as CFRP, PLA, ABS, and Wood all produced higher maximum payload capacities of 0.84107 kg, 0.87584 kg, 0.89571 kg, and 0.94040 kg, respectively. Only Aluminum Alloy performed worse, producing a maximum payload capacity of 0.73181 kilograms.

The second requirement for the drone arm design was that the engineering safety margin, represented by the Factor of Safety (FoS), must be ~1.5-2+ under the given loading conditions of the motor applied to the motor mount face, while a separate face on the root attachment flange was fixed to represent the attachment point to the main drone body. Although this is a simplified representation of the actual loading conditions experienced during flight, it still produced meaningful results for comparing the structural performance of each material. All materials passed the required safety criteria. In particular, GFRP produced a maximum Von Mises stress of 4.2546 MPa, a maximum displacement of 0.1655 mm, and a Factor of Safety of 70.512. However, GFRP was still not the highest-performing option. CFRP produced the lowest maximum displacement of 0.059081 mm and the highest Factor of Safety of 141.23, while Aluminum Alloy produced a maximum displacement of 0.059894 mm and a Factor of Safety of 64.937. Wood produced a higher maximum displacement of 0.41304 mm and a Factor of Safety of 18.943. The largest concern appeared with the plastic materials, specifically PLA and ABS. While both materials technically passed the FoS requirement, PLA produced a maximum displacement of 1.1798 mm with a Factor of Safety of 14.229, and ABS produced
a maximum displacement of 2.0652 mm with a Factor of Safety of 9.4714. These displacement values
may seem reasonable, however, when compared to the actual wall thickness of Design 1, which tapers down to approximately 1.0 mm near the motor mount, the issue becomes apparent. The motor thrust can not be assumed to be aligned with the vertical loading direction because the displacement is greater than twice the thickness of the thinnest section of the arm. In real world conditions, such large deformation would introduce vibrations and dynamic instability, referred to in drone applications as the "jello effect." Although PLA and ABS satisfy the numerical FoS requirement, their excessive deformation makes them more likely to fail as material choices for this application.

Finally, a cost optimization was performed to determine which material satisfied all numerical requirements while minimizing the total material cost. Although GFRP resulted in a total material cost of $12.12, it
was not the least expensive option. Wood produced the lowest material cost at only $1.62, followed by PLA and ABS at $2.83, Aluminum Alloy at $6.06, GFRP at $12.12, and CFRP at $24.24. Based solely
on the numerical optimization, Wood would therefore be selected as the optimal material since it also achieved the highest maximum payload capacity of 0.94040 kg while maintaining a Factor of Safety of 18.943. However, this optimization does not capture several important real-world engineering considerations. Since Wood is a natural material, its mechanical properties are not consistent due to grain orientation, knots, moisture absorption, and manufacturing inconsistencies. Consequently, despite its excellent numerical performance and exceptionally low cost, Wood was not considered the most practical material for a drone arm. At the other end of the spectrum, CFRP provided the highest structural performance but was ultimately deemed unnecessary when GFRP produced similarly strong results for nearly half the cost. In conclusion, Design 1 manufactured from GFRP provides the most balanced engineering solution by satisfying all design requirements while meeting an effective balance between structural performance, manufacturing practicality, material consistency, and overall cost.

Several limitations should be considered when interpreting these results. The accuracy of the finite element analysis depends on mesh size; therefore, a reasonably refined mesh that demonstrated satisfactory convergence of the results was used, although a more comprehensive mesh convergence study with further refinement should be performed in future work. The FEA also only analyzed a single drone arm rather
than the complete drone assembly, meaning interactions between the arms, central frame, fasteners, and motor mounting hardware were not included. In addition, the material models assumed isotropic behavior, which simplifies the actual behavior of composite materials such as GFRP, whose properties depend on fiber orientation and manufacturing processes. The applied loading conditions were also simplified by representing the motor thrust and motor weight as a single surface traction, without accounting for real flight effects such as vibration, acceleration, impact loading, aerodynamic forces, or changing thrust conditions. The calculated Factor of Safety did not account for fatigue, manufacturing defects, environmental effects, or long-term material degradation.

For future steps, the drone assembly will be tested using more realistic loading conditions and material properties, while validating the numerical results through physical prototype testing.

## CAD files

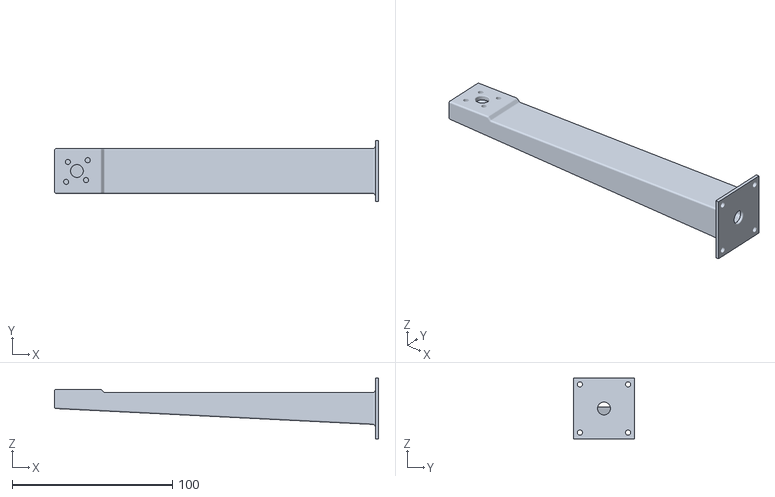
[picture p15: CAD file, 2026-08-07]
CAD-Designs/Design-1-Hollow-Tapered-Rectangular-Tube/Visualization_Only_Model.STL
202.0 x 38.0 x 38.0

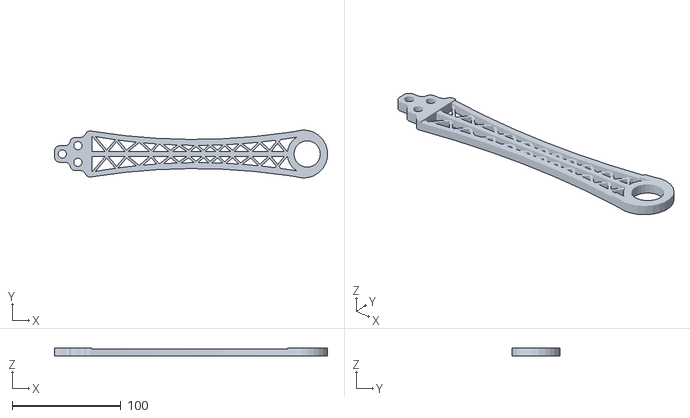
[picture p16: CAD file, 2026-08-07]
CAD-Designs/Design-2-Hollow-Truss-Structure/Design_2_CAD_Model.STL
251.1 x 44.1 x 7.80

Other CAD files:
CAD-Designs/Design-1-Hollow-Tapered-Rectangular-Tube/Design_1_CAD_Model.STEP

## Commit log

2026-08-06 CAD DESIGNS
2026-08-06 Create Drone Design1 CAD
2026-08-06 Update and rename Design_1_CAD_Model.STEP to d
    [Design_1_CAD_Model.STEP]
2026-08-06 Rename Results/Design_1_Results/Design 1 Drone Arm Face Labels.pdf to Results/Design_1_Results/FEA/Design 1 Drone Arm Face Labels.pdf
2026-08-06 Rename Results/Design_1_Results/Design 1 Material Cost Optimization Results.pdf to Results/Design_1_Results/Charts/Design 1 Material Cost Optimization Results.pdf
2026-08-06 Rename Results/Design_1_Results/Design 1 Maximum Payload Capacity.pdf to Results/Design_1_Results/Charts/Design 1 Maximum Payload Capacity.pdf
2026-08-06 Rename Results/Design_2_Results/Design 2 Drone Arm Face Labels.pdf to Results/Design_2_Results/FEA/Design 2 Drone Arm Face Labels.pdf
2026-08-06 Rename Results/Design_2_Results/Design 2 Material Cost Optimization Results.pdf to Results/Design_2_Results/Charts/Design 2 Material Cost Optimization Results.pdf
2026-08-06 Rename Results/Design_2_Results/Design 2 Maximum Payload Capacity.pdf to Results/Design_2_Results/Charts/Design 2 Maximum Payload Capacity.pdf
2026-08-06 Create Material Optimzation Table
2026-08-06 Rename Material Optimzation Table to Material Optimzation Table.txt
2026-08-06 Rename Design 1 Drone Arm Face Labels.pdf to Drone Arm Face Labels.pdf
2026-08-06 Rename Design 1 Material Cost Optimization Results.pdf to Material Cost Optimization Results.pdf
2026-08-06 Rename Design 1 Maximum Payload Capacity.pdf to Maximum Payload Capacity.pdf
2026-08-06 Rename Material Cost Optimization Results.pdf to Material Cost Optimization.pdf
2026-08-06 Rename Material Optimzation Table.txt to Material_Optimzation_Table.txt
2026-08-06 Rename Design 2 Material Cost Optimization Results.pdf to Material Cost Optimization Results.pdf
2026-08-06 Rename Design 2 Maximum Payload Capacity.pdf to Maximum Payload Capacity.pdf
2026-08-06 Rename Design 2 Drone Arm Face Labels.pdf to Drone Arm Face Labels.pdf
2026-08-07 Reorganize repository structure
    Reorganized project folders, improved naming consistency, and grouped documentation, CAD files, MATLAB files, and analysis results into a clearer repository structure.
    [Design_1_CAD_Model.STEP, Design_2_CAD_Model.STL]
2026-08-07 Fix CAD model file names in README
    Updated file names in README for consistency.
2026-08-07 Create MODEL FOR VIEWING ONLY.STL
    [MODEL FOR VIEWING ONLY.STL]
2026-08-07 Rename STL File for Viewing
    [Design-1-Visualization-Only-Model.STL]
2026-08-07 Rename STL File
    [Visualization-Only-Model.STL]
2026-08-07 Rename CAD model files in README
    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
2026-08-07 Fix hyphenation in README.md
    Corrected hyphenation in 'MATLAB-based' and 'thrust-to-weight' for consistency.
2026-08-08 Revise README for clarity and formatting improvements
    Updated project title, improved formatting, and clarified instructions for CAD file download and project execution.
2026-08-08 Revise README for improved documentation and links
    Updated README to include links to CAD designs, documentation, and MATLAB files. Enhanced structure and clarity of project instructions.
